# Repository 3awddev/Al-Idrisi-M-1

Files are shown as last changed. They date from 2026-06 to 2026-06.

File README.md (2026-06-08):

# Al-Idrisi-M1 — CanSat Flight Control System

> A complete end-to-end CanSat competition platform: dual-ESP32 flight computer, 3D-printable enclosure, and PyQt6 ground control station with real-time telemetry, 3D visualisation, and simulation.

---

## Table of Contents

1. [For Absolute Beginners](#for-absolute-beginners)
2. [For Aerospace & Software Engineers](#for-aerospace--software-engineers)
   - [Project Overview](#project-overview)
   - [Flight Hardware — Dual ESP32 Architecture](#flight-hardware--dual-esp32-architecture)
   - [3D CAD — Parametric CanSat Enclosure](#3d-cad--parametric-cansat-enclosure)
   - [CFC Software — Ground Control Station](#cfc-software--ground-control-station)
   - [Flight Firmware — Main ESP32](#flight-firmware--main-esp32)
   - [Flight Firmware — ESP32-CAM Coprocessor](#flight-firmware--esp32-cam-coprocessor)
   - [Telemetry & Command Protocols](#telemetry--command-protocols)
   - [Power Budget](#power-budget)
   - [Build Guide](#build-guide)
   - [Competition Workflow](#competition-workflow)

---

## For Absolute Beginners

### What is a CanSat?

A CanSat is a **miniature satellite** that fits inside a standard soda can (67 mm diameter × 120 mm tall). It's launched on a small rocket to ~800 m altitude, then descends by parachute while transmitting sensor data to a ground station on Earth. University and high-school teams worldwide build CanSats for the annual **CanSat Competition** organised by the American Astronomical Society.

Every CanSat must contain:
- A **flight computer** (microcontroller + sensors)
- A **radio** to transmit data back to the ground
- A **parachute** deployment mechanism
- A **battery** to power everything
- A **structural frame** (the "can" body)

### What does this project do?

This project is a **complete CanSat engineering kit** with three main parts:

```
┌─────────────────────────────────────────────────────────┐
│              AL-IDRISI-M1 SYSTEM OVERVIEW                │
├─────────────────────────────────────────────────────────┤
│                                                         │
│  ┌─────────────────┐    433 MHz LoRa    ┌─────────────┐│
│  │  FLIGHT SYSTEM  │ ◄──────────────►   │  GROUND      ││
│  │  (in the can)   │                    │  STATION     ││
│  │                 │                    │  (laptop)    ││
│  │  • ESP32 (main) │                    │              ││
│  │  • ESP32-CAM    │                    │  • Real-time  ││
│  │  • BMP280       │                    │    plots     ││
│  │  • MPU-6050     │                    │  • 3D model   ││
│  │  • INA219       │                    │  • Telemetry  ││
│  │  • NEO-6M GPS   │                    │    console    ││
│  │  • LoRa SX1278  │                    │  • Simulation ││
│  │  • MG90S servo  │                    │  • CSV export ││
│  │  • microSD card │                    │  • Command    ││
│  │  • 2S LiPo batt.│                    │    uplink     ││
│  └────────┬────────┘                    └──────────────┘│
│           │                                              │
│           ▼                                              │
│  ┌─────────────────┐                                     │
│  │  3D-PRINTED     │                                     │
│  │  ENCLOSURE      │                                     │
│  │  (67mm × 120mm) │                                     │
│  │                 │                                     │
│  │  • Electronics  │                                     │
│  │    bay (73mm)   │                                     │
│  │  • Bulkhead     │                                     │
│  │  • Parachute    │                                     │
│  │    bay (38mm)   │                                     │
│  └─────────────────┘                                     │
└─────────────────────────────────────────────────────────┘
```

1. **Flight System** — two ESP32 microcontrollers, sensors, radio, and servo packed inside the can. This is what flies on the rocket.

2. **3D-Printed Enclosure** — the physical can body designed in OpenSCAD. It holds everything together and separates at apogee to deploy the parachute.

3. **Ground Control Station (CFC)** — a desktop application you run on a laptop. It receives radio data, shows live plots, displays a 3D model of the satellite, and lets you send commands back to the CanSat.

### How does it all work?

1. You **program** both ESP32s with the flight firmware (using the Arduino IDE)
2. You **3D-print** the enclosure parts
3. You **assemble** everything inside the can (sensors, batteries, wiring)
4. You **launch** the CanSat on a rocket
5. During ascent, the flight computer **reads sensors** (altitude, temperature, GPS, orientation) and **transmits** all data via LoRa radio every second
6. Your laptop's **ground station** receives, plots, and logs all data in real time
7. At apogee (~800 m), you send a **command via LoRa** to release the parachute
8. The CanSat **descends safely**, streaming data all the way down

---

## For Aerospace & Software Engineers

### Project Overview

**Al-Idrisi-M1** (named after the 12th-century cartographer Muhammad al-Idrisi) is a CanSat Competition 2026 entry. The design uses a **dual-ESP32 architecture** where one ESP32 (NodeMCU-32S) handles all sensors, radio, GPS, servo, and logging, while a second ESP32-CAM (AI-Thinker) handles only the camera — connected via UART.

This architecture was chosen because the ESP32-CAM's camera parallel bus occupies GPIOs 12–15 and 4–5, which would conflict with dedicated SPI (VSPI: 23/19/18/5) and SD card (GPIO15). Splitting the workload avoids all pin conflicts while allowing the main ESP32 full access to VSPI for the LoRa + SD bus.

### Flight Hardware — Dual ESP32 Architecture

#### Block Diagram

```
                         ┌──────────────────────────────────┐
                         │  2S LiPo 7.4V (1000mAh)          │
                         │  ──→ Pololu 5V 2A Regulator      │
                         │       ──→ 5V rail                │
                         └────────────┬──────────┬───────────┘
                                      │          │
               ┌──────────────────────┼──────────┼───────────────────┐
               │        5V            │    5V    │     5V            │
          ┌────▼────┐          ┌──────▼─────┐   ┌▼──────┐           │
          │  Main   │◄──UART──►│ ESP32-CAM  │   │ MG90S │           │
          │  ESP32  │  GPIO16/ │ AI-Thinker │   │ Servo │           │
          │Dev Board│   17     │  OV2640    │   │GPIO25 │           │
          └┬──┬──┬──┘          └────────────┘   └───────┘           │
           │  │  │                                                    │
      ┌────┘  │  └──────┐                                           │
      │       │         │                                            │
 ┌────▼──┐ ┌──▼──┐ ┌───▼──────┐  ┌────────┐                        │
 │ NEO-6M│ │ I2C │ │ LoRa     │  │microSD │                        │
 │  GPS  │ │ Bus │ │ SX1278   │  │(SPI CS │                        │
 │UART1  │ │21/22│ │433MHz SPI│  │GPIO15) │                        │
 │GPIO13/│ │     │ │CS=GPIO5  │  └────────┘                        │
 │  14   │ │ BMP │ │RST=GPIO2 │                                     │
 └───────┘ │280  │ │DIO0=GPIO4│                                     │
           │ MPU-│ └──────────┘                                     │
           │6050 │                                                  │
           │ INA │                                                  │
           │219  │                                                  │
           └─────┘                                                  │
└───────────────────────────────────────────────────────────────────┘
```

#### Component Details

| Component | Interface | Address / Freq | Purpose |
|---|---|---|---|
| **BMP280** | I2C (0x76) | 100 kHz | Barometric pressure + temperature → altitude via standard atmosphere equation |
| **MPU-6050** | I2C (0x68) | 100 kHz | 6-axis IMU: 3-axis gyroscope (±250°/s) + 3-axis accelerometer (±2g) for orientation and dynamics |
| **INA219** | I2C (0x40) | 100 kHz | 0–26V bus voltage, ±3.2A shunt current monitoring |
| **NEO-6M** | UART1 (GPIO13/14) | 9600 8N1 | GPS position, time, altitude, number of satellites. NMEA $GPGGA/$GNGGA parsed onboard |
| **SX1278** | SPI VSPI (CS=5, RST=2, DIO0=4) | 433 MHz, SF7, BW125kHz, CR4/5, 17dBm | LoRa telemetry downlink (1 Hz CSV) + command uplink receiver |
| **microSD** | SPI VSPI (CS=15, shared MOSI/MISO/SCLK) | — | Flight data CSV logging + JPEG image archival |
| **MG90S** | PWM (GPIO25) | 50 Hz | 180° servo for parachute release mechanism |
| **ESP32-CAM** | UART2 (GPIO16/17) | 115200 baud | OV2640 camera, SVGA (800×600) JPEG capture on command, flash LED on GPIO4 |

#### I2C Bus

All three I2C sensors share the same bus (GPIO21 SDA, GPIO22 SCL). Pull-up resistors to 3.3V (4.7 kΩ typical) are required if not present on breakout boards.

| Device | Address | Conflicts |
|---|---|---|
| BMP280 | 0x76 | Jumper to 0x77 if needed |
| MPU-6050 | 0x68 | AD0 high → 0x69 |
| INA219 | 0x40 | A0/A1 strapping → 0x40–0x4F |

#### UART Configuration

| Port | TX | RX | Baud | Device |
|---|---|---|---|---|
| Serial (UART0) | GPIO1 | GPIO3 | 115200 | USB debug / programming |
| UART1 | GPIO14 | GPIO13 | 9600 | NEO-6M GPS |
| UART2 | GPIO17 | GPIO16 | 115200 | ESP32-CAM |

#### SPI Bus

VSPI is shared between LoRa (CS=5) and SD card (CS=15). The bus runs at ESP32 default SPI clock (~10 MHz). Both devices share MOSI (GPIO23), MISO (GPIO19), and SCLK (GPIO18).

#### Key Design Decision — Dual ESP32

The single ESP32-CAM cannot simultaneously drive:
- OV2640 parallel camera bus (GPIOs: 0, 4, 5, 18, 19, 21, 22, 23, 25, 26, 27, 34, 35, 36, 39)
- And VSPI (GPIO 5, 18, 19, 23) for LoRa + SD

The camera bus overlaps with VSPI on GPIOs 5, 18, 19, 23, and with the servo on GPIO25. Adding an SD card would require GPIO15 (another conflict).

**Solution:** A dedicated main ESP32 (NodeMCU-32S) handles all peripherals; the ESP32-CAM handles only the camera. They communicate over UART2 at 115200 baud with a binary protocol.

### 3D CAD — Parametric CanSat Enclosure

#### Design Philosophy

The enclosure is designed exclusively with **OpenSCAD primitives** (cylinder, difference, hull, rotate_extrude) — no external libraries. Every dimension is parameterised at the top of the file. Resolution is set to `$fn=80` for printed parts.

#### Physical Specifications

| Parameter | Value | Tolerance |
|---|---|---|
| Outer diameter | 67 mm | ±0.2 mm (fits standard soda can launcher) |
| Wall thickness | 3 mm | 2 shells with 0.4 mm nozzle |
| Total height | 120 mm | 3 (cap) + 73 (electronics) + 3 (bulkhead) + 38 (parachute) + 3 (cap) |
| Internal diameter | 61 mm | Accommodates 60 mm PCB trays |
| PCB tray PCD | 52 mm | 4× M2.5 threaded inserts |
| Weight (printed) | ~80 g PETG | 0.15 mm layer height |

#### Height Budget

```
z=117 ┌────────────────────┐  ─── Top cap (3 mm)
       │                    │      M3 eye-bolt holes at x=±15
       │   PARACHUTE BAY    │
z= 79  │   38 mm internal   │      Spring seat ring at z=3
       │                    │      Vent hole at mid-height (0°)
       │                    │      Locking pin at z=2 (225°)
z= 76 ─╊━━━━ BULKHEAD 3mm ━╋───  4× M2.5 at 45°, locking pin 
       │                    │      hole at 225°, 6× vent slots
       │ ELECTRONICS BAY    │
       │   73 mm internal   │
       │                    │
       │ Tray 3 @ z=54      │      LoRa module, SD card
       │ Tray 2 @ z=36      │      Main ESP32, BMP280, MPU-6050
       │ Tray 1 @ z=18      │      ESP32-CAM, INA219, Pololu reg
       │                    │
       │ Battery @ z=0-12   │      2S LiPo 54×30×12 mm
z=  0 ─┼────────────────────┼───
z= -3 ─┴────────────────────┴─── Bottom cap (3 mm)
```

#### Cutout Positions (Electronics Bay)

| Feature | Z position (mm) | Angle (°) | Size | Purpose |
|---|---|---|---|---|
| Access port | 40 | 0 | 16×6 mm (rounded) | USB cable during development |
| Camera lens | 20 | 45 | 10 mm Ø | ESP32-CAM OV2640 lens |
| Servo horn | 53 | 75 | 8 mm Ø | MG90S spline access |
| SMA bulkhead | 63.5 | 135 | 11 mm hex | LoRa antenna connector |
| Slide switch | 9.5 | 180 | 13×4 mm (rounded) | Battery power switch |
| LED indicators | 15, 19 | 180 | 3 mm Ø | Status LEDs |
| Battery straps | 5, 15 | 90/270 | 3 mm Ø | Zip-tie anchor points |

#### Threaded Insert Specifications

| Location | Thread | Hole Ø | PCD | Count |
|---|---|---|---|---|
| PCB trays | M2.5 | 2.7 mm | 52 mm | 4 per tray |
| Bulkhead rim (both tubes) | M2.5 | 2.7 mm | 52 mm | 4 per side |
| Top cap (eye bolt) | M3 | 3.2 mm | 30 mm | 2 |
| Bottom cap (tray mount) | M2.5 | 2.7 mm | 52 mm | 4 |

#### Parachute Deployment Mechanism

```
BEFORE RELEASE:                    AFTER RELEASE:

┌────────────────────┐             ┌────────────────────┐
│ Top cap            │             │ Top cap (on ground)│
│ (tethered)         │             │  + parachute       │
│                    │             │                    │
│ Parachute pack     │  Spring     │ ◄─ Spring pushes   │
│  (compressed)      │  ────►      │     parachute out  │
│                    │             │                    │
│┄┄┄ Spring seat ┄┄┄│             │                    │
│                    │             │                    │
│ Locking pin ──►    │             │ Pin retracted      │
│  (through          │             │  by servo push-rod │
│   bulkhead+wall)   │             │                    │
╞═══ BULKHEAD ═══════╡             ╞═══ BULKHEAD ═══════╡
│ Electronics        │             │ Electronics        │
│  (undisturbed)     │             │  (undisturbed)     │
└────────────────────┘             └────────────────────┘

Mechanism:
1. A compression spring sits on the spring-seat ring at z=79
2. The parachute pack is compressed above the spring
3. A 3.5 mm locking pin passes through the upper tube wall at 
   z=78 (225°) and the bulkhead at the same position
4. The MG90S servo at z=53 (75°) actuates a push-rod or 
   Bowden cable that goes through the bulkhead at 225°
5. At apogee, GCS sends "MEC 1 ON" → servo rotates 180°
   → pin retracts → spring pushes parachute out
```

#### Print Settings (Recommended)

| Setting | Value |
|---|---|
| Material | PETG (preferred) or PLA+ |
| Layer height | 0.15 mm |
| Nozzle | 0.4 mm |
| Perimeters | 3 |
| Top/bottom layers | 4 |
| Infill | 20% gyroid |
| Supports | None (design is self-supporting when printed tube-axis-horizontal) |
| Orientation | Tube axis horizontal on bed (`rotate([0,-90,0])` in source) |
| Bed temp | 70°C PETG, 60°C PLA |
| Extruder temp | 235°C PETG, 210°C PLA |

#### OpenSCAD File Structure

The file `cansat_enclosure.scad` is structured as:

```
User Parameters ──► Derived Constants
       │
       ├── Helpers (cr, tube, rh, rs)
       ├── Modules (bottom_cap, top_cap, lower_tube, upper_tube, 
       │            bulkhead, pcb_tray, standoff, parachute_anchor)
       └── Assembly (positions all modules + transparent placeholders)
```

Key design patterns:
- **`rh(d, z, a)`** — Circular radial hole: cylinder of diameter `d` aligned along +X (via `rotate([0,90,0])`), spanning `tube_od×2` (guarantees wall penetration regardless of diameter), rotated to angle `a` about Z, translated to height `z`
- **`rs(w, h, cr, z, a)`** — Rounded-rectangular radial slot: hull of 8 spheres (4 corners × 2 depths ±tube_od) for guaranteed wall penetration
- **Chamfers**: `rotate_extrude` + `polygon` triangle for 1 mm 45° chamfers on tube edges (avoids `difference`-cancellation bug)

### CFC Software — Ground Control Station

The CFC (CanSat Flight Control) is a **PyQt6 desktop application** with pyqtgraph-based real-time plotting, an OpenGL 3D visualisation, serial/LoRa telemetry receiver, command uplink, simulation engine, and CSV logging.

#### Architecture

```
                    ┌─────────────────────────────────────────┐
                    │              QMainWindow                 │
                    │  (src/ui_layout.py)                     │
                    ├──────────┬──────────┬───────────────────┤
                    │ Left     │ Central  │ Right Dock        │
                    │ Dock     │ Area     │ (320px min)       │
                    │ (240px)  │          │                   │
                    ├──────────┼──────────┤  3D Simulation    │
                    │Resources │ Plot Grid│  (GLViewWidget)   │
                    │ Tree     │ (5 plots)│                   │
                    │          │          │  ┌─────────────┐  │
                    │ Hardware │  Altitude│  │ CanSat body  │  │
                    │ Telemetry│   Voltage│  │ + orientation│  │
                    │ Commands │   Current│  │ + altitude   │  │
                    │          │  Accel(3)│  │ + ground     │  │
                    │          │  Gyro(3) │  │ + launch pad │  │
                    └──────────┴──────────┴───────────────────┘
                    │       Bottom Dock ("Console")            │
                    │  ┌──────────────────┬──────────────────┐ │
                    │  │ Message Console  │ Packet Monitor   │ │
                    │  │                  │ Rcvd / Lost / %  │ │
                    │  └──────────────────┴──────────────────┘ │
                    └──────────────────────────────────────────┘
```

#### Dependencies

| Package | Version | Purpose |
|---|---|---|
| `PyQt6` | ≥6.5 | GUI framework (QMainWindow, docks, signals/slots) |
| `pyqtgraph` | ≥0.13 | Real-time plotting + OpenGL 3D view |
| `pandas` | ≥2.0 | In-memory telemetry storage + CSV export |
| `pyserial` | ≥3.5 | Serial port enumeration (QSerialPortInfo) |
| `qdarkstyle` | ≥3.2 | Dark/light theme switching |
| `PyOpenGL` | ≥3.1 | OpenGL context for 3D visualizer |
| `numpy` | *(bundled with pyqtgraph)* | Mesh math, rotation matrices |

Install: `pip install -r requirements.txt`

#### File Map — `src/`

| File | Lines | Responsibility |
|---|---|---|
| `main.py` | 26 | App entry point, QApplication init, dark theme |
| `ui_layout.py` | 435 | MainWindow: toolbars, docks, wire signals, serial port dialog |
| `telemetry_engine.py` | 123 | QThread: serial I/O, mock generator, CSV parsing, poll timer |
| `telemetry_packet.py` | 84 | TelemetryPacket dataclass (22 fields) + `from_csv()` parser |
| `commands.py` | 37 | CommandBuilder (ST, CAL, SIM, SIMP, MEC, CX) + CommandSender signal |
| `mock_generator.py` | 115 | 4-phase flight profile: ascent (30s→300m), release, descent, landed |
| `simulation_engine.py` | 93 | QThread: pressure CSV reader, 1 Hz SIMP uplink |
| `data_logger.py` | 45 | pandas DataFrame: append, sequence checking, CSV export |
| `plots.py` | 132 | BasePlot + 5 specialised plot widgets (altitude, voltage, current, accel, gyro) |
| `visualizer_3d.py` | 430 | OpenGL 3D: Blender-style camera, CanSat mesh with fins + nose cone, auto-rotation |
| `ui_tree.py` | 68 | QTreeWidget: mission/hardware/telemetry/commands trees |
| `ui_console.py` | 77 | MessageConsole + PacketMonitor (received/lost/success %) |

#### Threading Model

```
 ┌──────────────────────┐
 │  MAIN THREAD         │
 │  (QApplication)      │
 │                      │
 │  • UI updates        │
 │  • Plot data append  │
 │  • 3D repaint        │
 │  • Signal handlers   │
 │  • 30ms refresh timer│
 └────────┬─────────────┘
          │ Signals
          │
 ┌────────▼─────────────┐     ┌──────────────────────────┐
 │  TELEMETRY ENGINE    │     │  SIMULATION ENGINE       │
 │  (QThread)           │     │  (QThread)               │
 │                      │     │                          │
 │  • 50ms poll timer   │     │  • 50ms poll timer        │
 │  • Serial read/write │     │  • CSV pressure loading   │
 │  • Mock generation   │     │  • 1 Hz SIMP emission    │
 │  • CSV parsing       │     │                          │
 │  • Command echo      │     │                          │
 └──────────────────────┘     └──────────────────────────┘
```

Both threads use **QTimers** for polling (not blocking loops), which allows clean start/stop from the main thread without join/detach issues. Cross-thread communication is via **Qt Signals** (thread-safe, queued connections).

- `packet_received(TelemetryPacket)` → UI updates, plots, data logger
- `status_message(str)` → Console log
- `serial_error(str)` → Error handling, disconnection
- `command_to_send(str)` → Serial write on telemetry thread
- `pressure_uplink(float)` → SIMP command to flight computer

#### Mock Telemetry Generator

When no serial hardware is available, the `MockGenerator` produces a realistic 4-phase flight profile:

| Time (s) | Phase | Altitude | State | Mode |
|---|---|---|---|---|
| 0–30 | Ascent | 0 → 300 m (linear) | ASCENT | FLIGHT |
| 30–35 | Apogee | 300 m ±5 | RELEASE | FLIGHT |
| 35–120 | Descent | 300 → 0 m (parabolic) | DESCENT | FLIGHT |
| 120+ | Landed | 0 ±0.5 | LANDED | IDLE |

Voltage decays linearly from 16.8 V at 0.6 mV/s (realistic for 2S LiPo under ~350 mA load). All sensor values include Gaussian noise (±0.5°C, ±10 Pa, ±0.02 V, ±0.01 A, ±2°/s gyro, ±1 m/s² accel).

#### 3D Visualizer

The `BlenderStyleGLViewWidget` (subclass of `GLViewWidget`) implements:

| Interaction | Action |
|---|---|
| MMB drag | Orbit camera |
| Shift + MMB drag | Pan (view-upright) |
| Ctrl + MMB drag | Zoom (via `distance` animation) |
| Scroll wheel | Zoom (animated, 0.999^delta factor) |
| Ctrl + scroll | FOV adjustment |
| MMB double-click | Reset to default view (distance=45, elev=15, azimuth=0) |

**Auto-rotation**: When no telemetry has arrived for 2+ seconds, the CanSat model slowly spins (0.5°/tick at 33 ms = ~15°/s) around the Y axis. Real orientation data (roll/pitch/yaw from MPU-6050) immediately suppresses auto-spin.

The 3D scene includes:
- Checkerboard ground plane (80×80 units at z=0)
- Launch pad (3-cylinder stage with green inner ring)
- CanSat body (cylinder mesh, 0.35 radius × 0.80 height, blue)
- Nose cone (red cone, 0.35 radius × 0.35 height)
- 4 tail fins (red, 0.4 span × 0.25 length)
- 2 white stripes (decorative rings)
- Vertical reference line (altitude indicator, translucent blue)
- Axis indicator (3-colour, in corner)

The altitude is scaled by `ALT_SCALE = 10` (1 unit = 10 m real altitude) to keep the model visible within the view frustum.

#### Telemetry Protocol — 22-field CSV

```
TEAM_ID, MISSION_TIME, PACKET_COUNT, MODE, STATE,
ALTITUDE, TEMPERATURE, PRESSURE, VOLTAGE, CURRENT,
GYRO_R, GYRO_P, GYRO_Y, ACCEL_R, ACCEL_P, ACCEL_Y,
GPS_TIME, GPS_ALTITUDE, GPS_LATITUDE, GPS_LONGITUDE,
GPS_SATS, CMD_ECHO
```

Transmitted via LoRa at 1 Hz (every 1000 ms, not polling-loop-gated to avoid drift). The main ESP32 formats the line with `snprintf` and sends it via `LoRa.beginPacket()` / `LoRa.print()` / `LoRa.endPacket()`.

#### Command Protocol

Commands are sent **from GCS → Flight Computer** via LoRa (or serial during testing).

```
CMD,<TEAM_ID>,<ACTION>[,<PARAMETER>]
```

| Command | Example | Action |
|---|---|---|
| ST | `CMD,1234,ST,3600` | Start mission; set mission_time to 3600 s; enter FLIGHT/ASCENT |
| CAL | `CMD,1234,CAL` | Zero IMU bias (gyro/accel) + altimeter |
| SIM ENABLE | `CMD,1234,SIM,ENABLE` | Enter simulation mode (accept SIMP overrides) |
| SIMP | `CMD,1234,SIMP,95000` | Override pressure sensor with 95000 Pa |
| MEC | `CMD,1234,MEC,1,ON` | Set servo to 180° (parachute release) |
| CX | `CMD,1234,CX,ON` | Request camera capture from ESP32-CAM |

#### Simulation Engine

The `SimulationEngine` QThread loads a CSV file with `TIME,PRESSURE` columns and uplinks pressure values at 1 Hz via SIMP commands. This simulates a realistic pressure profile during flight, allowing full GCS testing without a real CanSat or rocket.

The sample file `sample_pressure.csv` contains a 120-second profile: 30 s ascent (1013.25 → 977.00 hPa), 5 s apogee, 55 s descent, 30 s ground.

#### Data Logging

All telemetry is stored in a **pandas DataFrame** (max 600 rows rolling window) and can be exported to CSV via the Export button (`_on_export`). The `DataLogger` tracks packet sequence numbers and reports lost packets (gaps in `PACKET_COUNT`).

### Flight Firmware — Main ESP32

**File:** `flight/main_esp32/main_esp32.ino` (592 lines)

#### Initialisation Sequence

```
1. Serial.begin(115200)               // Debug output
2. Wire.begin(21, 22)                 // I2C at 100 kHz
3. BMP280.begin()                     // Read calib, set normal mode
4. MPU6050.begin()                    // Wake from sleep, set ±250°/s, ±2g
5. INA219.begin()                     // Config: 32V, 3.2A range
6. gps_ser.begin(9600, SERIAL_8N1, 13, 14)
7. cam_ser.begin(115200, SERIAL_8N1, 16, 17)
8. LoRa.setPins(5, 2, 4)             // CS, RST, DIO0
9. LoRa.begin(433E6)                  // SF7, BW125kHz, CR4/5, 17dBm
10. servo.attach(25); servo.write(0)  // MG90S: 0° = closed
11. SD.begin(15)                      // Create /flight/ dir, open CSV
```

#### Main Loop (1 Hz)

```
timer ≥ 1000ms?
├── Read BMP280 → temperature, pressure
│   └── If SIM mode: override pressure from SIMP command
│   └── altitude = 44330 × (1 - (p/p₀)^(1/5.255))
├── Read MPU-6050 → accel_r/p/y, gyro_r/p/y
│   └── Subtract calibration bias
├── Read INA219 → voltage, current
├── Flight state machine:
│   LAUNCH_WAIT + alt ≥ 10m → ASCENT + FLIGHT
├── Format 22-field CSV line
├── LoRa.beginPacket → LoRa.print → LoRa.endPacket
├── Append to SD CSV file
├── Serial.println (debug)
└── process_cam_uart()     // Check for JPEG from ESP32-CAM
```

#### Sensor Drivers (all inline, no libraries)

All three I2C sensor drivers are implemented **from scratch** using `Wire` — no Adafruit or SparkFun libraries. This keeps the firmware self-contained and avoids library version conflicts.

- **BMP280**: Full compensation from factory calibration registers (0x88–0x9F). 20-bit raw pressure/temperature → 32-bit compensated values per Bosch datasheet.
- **MPU-6050**: Direct register reads (0x3B–0x44). FIFO not used (polled reads at 1 Hz). Raw ±2g / ±250°/s.
- **INA219**: 12-bit shunt + bus voltage reads. Shunt voltage → current via 0.1 Ω sense resistor (0.1 mA/LSB).

#### GPS NMEA Parser

Parses `$GPGGA` and `$GNGGA` sentences (up to 256 bytes buffered). Extracts:
- Time (HH:MM:SS from UTC)
- Latitude/Longitude (DDMM.MMMM → DD.DDDDDD)
- Number of satellites
- GPS altitude

DM.MMMM → decimal conversion:
```
lat_dec = floor(raw/100) + (raw - floor(raw/100)*100) / 60
```

#### Image Reception State Machine

Handles the binary protocol from ESP32-CAM (`0xAA 0xBB <4-byte length> <JPEG data> DONE\r\n`). Images are saved to `/flight/img_<timestamp>.jpg` on the microSD card. Buffer: 60 kB (max SVGA JPEG fits within ~50 kB).

```
IMG_HDR1 → 0xAA → IMG_HDR2 → 0xBB → IMG_LEN → (4 bytes) → IMG_DATA → (len bytes) → save to SD → IMG_IDLE
     │          │          │
     └─ no ─────┴─ no ─────┴─ no ────→ IMG_HDR1 (reset)
```

### Flight Firmware — ESP32-CAM Coprocessor

**File:** `flight/esp32_cam/esp32_cam.ino` (123 lines)

#### UART Protocol

| Direction | Message | Response |
|---|---|---|
| Main → CAM | `CX ON\r\n` | `0xAA 0xBB <len:4> <JPEG> DONE\r\n` |
| Main → CAM | `CX OFF\r\n` | `OK\r\n` |

#### Camera Configuration

- **Resolution:** SVGA (800×600)
- **Format:** JPEG
- **Quality:** 12 (good balance of size/clarity)
- **PSRAM:** Required (AI-Thinker board has 4 MB PSRAM)
- **Clock:** XCLK at 20 MHz
- **Brown-out:** Disabled during JPEG transmission (high current draw)

#### Power States

| State | Camera Power | Current Draw |
|---|---|---|
| Idle (CX OFF) | Deinitialised via `esp_camera_deinit()` | ~20 mA |
| Capture (CX ON) | Active via `esp_camera_init()` | ~180 mA |

The flash LED on GPIO4 is illuminated during capture for 200 ms.

### Power Budget

| Component | Idle (mA) | Active (mA) | Notes |
|---|---|---|---|
| Main ESP32 | 50 | 80 | Wi-Fi off, LoRa + SD active |
| ESP32-CAM | 20 | 180 | Camera deinit'd / active + capture |
| LoRa SX1278 | 0.1 | 30 | LowPower idle / TX 17dBm |
| NEO-6M GPS | 45 | 45 | Always on, continuous fix |
| MG90S Servo | 5 | 250 (stalled) | Idle 0°, release 180° |
| 3× I2C sensors | 2 | 5 | BMP280+MPU6050+INA219 |
| **Total** | **~120 mA** | **~590 mA** | Peak with camera + servo |

A **2S 1000 mAh LiPo** provides ~1.7 hours endurance (at average 350 mA). The Pololu 5V 2A regulator handles all loads with margin.

### Build Guide

#### Step 1: 3D Printing

1. Install OpenSCAD from openscad.org
2. Open `C:\Users\El4v\Music\cansat_enclosure.scad`
3. Adjust parameters at top of file if needed (diameters, heights)
4. Press F6 to render (may take 30–60 seconds)
5. Press F7 to export STL
6. Slice in PrusaSlicer / Cura / OrcaSlicer with settings above
7. Print each part: bottom cap, lower tube, upper tube, bulkhead, 3× PCB trays, 12× standoffs, top cap
8. Tap M2.5 holes with M2.5 tap; insert heat-set threaded inserts where needed

#### Step 2: Program ESP32-CAM

1. Connect ESP32-CAM to USB-UART adapter (GPIO0→GND for flash)
2. Open `flight/esp32_cam/esp32_cam.ino` in Arduino IDE
3. Board: `AI-Thinker ESP32-CAM`, Partition: `Huge APP (3MB No OTA)`, PSRAM: Enabled
4. Upload at 115200 baud
5. Remove GPIO0 jumper, press RST

#### Step 3: Program Main ESP32

1. Connect NodeMCU-32S via USB
2. Open `flight/main_esp32/main_esp32.ino` in Arduino IDE
3. Board: `ESP32 Dev Module`, Partition: `Default 4MB with spiffs`
4. Upload at 921600 baud
5. Open Serial Monitor at 115200 baud — verify "BMP280 OK", "MPU6050 OK", "LoRa OK", etc.

#### Step 4: Assemble Electronics

Refer to wiring tables above. Assembly order:
1. Install threaded inserts in 3D-printed parts
2. Mount standoffs + PCB trays inside lower tube
3. Populate components per layout table:
   - Battery floor: 2S LiPo + switch + LEDs (zip-tie through strap holes)
   - Tray 1: ESP32-CAM + INA219 + Pololu regulator
   - Tray 2: Main ESP32 + BMP280 + MPU-6050
   - Tray 3: LoRa module + SD card module
4. Wire all power + I2C + SPI + UART buses
5. Fit bulkhead + upper tube with spring + parachute pack
6. Locking pin through 225° holes (bulkhead + upper tube wall)
7. Attach servo push-rod to locking pin
8. Close with top cap (eye-bolt through M3 holes, shock cord to parachute anchor)
9. Calibrate M2.5 rim screws to hold bulkhead securely

#### Step 5: Install & Run GCS

```bash
cd al-idrisi-m1
pip install -r requirements.txt
python main.py
```

Boot sequence:
1. Window appears with dark theme, 3D dock on right
2. Click **Mock OFF** → becomes **Mock ON** → telemetry starts
3. Plots populate with mock data, 3D model spins (auto-rotation)
4. Click **Connect** → select COM port → real telemetry from flight computer
5. Click **ST** → sends mission start time → flight enters ASCENT mode
6. Click **CAL** → calibrates IMU + altimeter bias
7. Click **SIM** → load pressure CSV → starts simulation mode
8. Click **MEC** → sends servo release command
9. Click **Export CSV** → save flight data for post-analysis

### Competition Workflow

```
PRE-LAUNCH:
1. Power on CanSat → mode = LAUNCH_WAIT
2. Connect GCS → verify telemetry (altitude ~0 m, voltage >7.0 V, GPS fix)
3. Click CAL → capture sensor biases
4. Wait for LCO (Launch Control Officer) countdown

LAUNCH:
5. Rocket lifts off; CanSat accelerates
6. At 10 m altitude → mode auto-switches to ASCENT + FLIGHT
7. GCS plots altitude in real time, 3D model rises above ground

APOGEE (≈800 m, ~30 s after launch):
8. Judge provides pressure CSV for SIMP simulation OR
   Real flight: click MEC 1 ON → servo releases parachute

DESCENT:
9. Parachute deploys, descent rate ≈10 m/s
10. GCS tracks GPS coordinates, 3D model descends
11. On-ground recovery team follows GPS to landing site

POST-FLIGHT:
12. Export CSV → submit to competition judges
13. Retrieve SD card for camera images
14. Print flight log from GCS console
```

---

## Repository Structure

```
al-idrisi-m1/
├── main.py                        # GCS application entry point
├── requirements.txt               # Python dependencies
├── sample_pressure.csv            # 120-second simulation pressure profile
├── README.md                      # This file
├── C:\Users\El4v\Music\cansat_enclosure.scad   # OpenSCAD enclosure
├── flight/
│   ├── README.md                  # Flight system build guide
│   ├── main_esp32/
│   │   └── main_esp32.ino         # Main flight computer firmware
│   └── esp32_cam/
│       └── esp32_cam.ino          # Camera coprocessor firmware
└── src/
    ├── __init__.py
    ├── main.py                    # (re-exported by root main.py)
    ├── ui_layout.py               # MainWindow, docks, toolbars
    ├── telemetry_engine.py         # Serial/mock thread
    ├── telemetry_packet.py         # 22-field dataclass + CSV parser
    ├── commands.py                 # CommandBuilder + CommandSender
    ├── mock_generator.py           # 4-phase mock flight profile
    ├── simulation_engine.py        # Pressure CSV simulation thread
    ├── data_logger.py              # pandas DataFrame logger + export
    ├── plots.py                    # 5 real-time pyqtgraph plots
    ├── visualizer_3d.py            # OpenGL CanSat + auto-rotation
    ├── ui_tree.py                  # Resources QTreeWidget
    └── ui_console.py               # Console + packet monitor
```

---

## License

Educational / competition use. No warranty expressed or implied.

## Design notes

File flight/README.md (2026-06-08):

# CanSat Flight System — ESP32 Dual-Processor

## Architecture

```
                      ┌─────────────────────────────────┐
  4×18650 (4S) ──→    │  Pololu 5V 2A Regulator         │
  12–16.8V             │  (4.5–28V input → 5V output)    │
                      └──────────┬──────────────────────┘
                                 │ 5V rail
              ┌──────────────────┼──────────────────┐
              │                  │                  │
        ┌─────▼──────┐    ┌─────▼──────┐     ┌─────▼──────┐
        │  Main ESP32 │    │ ESP32-CAM  │     │   Servo    │
        │ (DevKitC /  │◄──►│ (AI-Thinker)│     │   MG90S    │
        │  NodeMCU)   │UART│  OV2640    │     │  GPIO25    │
        └──┬──┬──┬──┬─┘    └────────────┘     └────────────┘
           │  │  │  │
      ┌────┘  │  │  └──────┐
      │       │  │         │
 ┌────▼──┐ ┌──▼──▼──┐ ┌───▼────┐  ┌───────────┐
 │  GPS  │ │ I2C Bus│ │  LoRa  │  │  microSD  │
 │ NEO-6M│ │GPIO21/22│ │SX1278  │  │  (SPI CS: │
 │UART1  │ │        │ │SPI VSPI│  │   GPIO15) │
 │GPIO13/│ │ BMP280 │ │GPIO5 CS│  └───────────┘
 │14     │ │ MPU6050│ │GPIO4   │
 └───────┘ │ INA219 │ │DIO0    │
           └────────┘ │GPIO2   │
                      │RST     │
                      └────────┘
```

## Bill of Materials

| Component | Qty | Purpose |
|---|---|---|
| ESP32 Dev Board (NodeMCU-32S / ESP32-DevKitC) | 1 | Main flight computer |
| AI-Thinker ESP32-CAM (OV2640) | 1 | Camera coprocessor |
| BMP280 | 1 | Temperature & pressure sensor (I2C) |
| MPU-6050 | 1 | 6-axis IMU (I2C) |
| INA219 | 1 | Voltage & current sensor (I2C) |
| NEO-6M GPS Module | 1 | GPS receiver (UART) |
| LoRa SX1278 433MHz Module | 1 | Telemetry radio (SPI) |
| MG90S Micro Servo | 1 | Canopy release mechanism |
| 4×18650 Lithium-Ion Cells (4S) | 4 | Battery: 14.8V nom, 16.8V full, 12.0V cut-off |
| Pololu 5V 2A Step-Down Regulator | 1 | Powers both ESP32 boards from 4S battery |
| microSD Card (16GB+) | 1 | Flight data & image logging |
| ¼-wave 433 MHz Antenna | 1 | For LoRa module |
| Passive buzzer (optional) | 1 | Audio feedback |

## Wiring

### Main ESP32 Pinout

| Main ESP32 GPIO | Connection | Peripheral |
|---|---|---|
| GPIO21 (SDA) | SDA bus | BMP280 SDA, MPU-6050 SDA, INA219 SDA |
| GPIO22 (SCL) | SCL bus | BMP280 SCL, MPU-6050 SCL, INA219 SCL |
| GPIO23 (MOSI) | VSPI MOSI | SX1278 MOSI, SD MOSI |
| GPIO19 (MISO) | VSPI MISO | SX1278 MISO, SD MISO |
| GPIO18 (SCLK) | VSPI SCLK | SX1278 SCLK, SD SCLK |
| GPIO5 (CS) | SPI CS | SX1278 NSS |
| GPIO15 (CS) | SPI CS | microSD card CS |
| GPIO4 | DIO0 | SX1278 DIO0 (interrupt) |
| GPIO2 | RST | SX1278 Reset |
| GPIO13 (RX1) | UART1 RX | NEO-6M GPS TX (yellow) |
| GPIO14 (TX1) | UART1 TX | NEO-6M GPS RX (green) |
| GPIO16 (RX2) | UART2 RX | ESP32-CAM TX (GPIO1) |
| GPIO17 (TX2) | UART2 TX | ESP32-CAM RX (GPIO3) |
| GPIO25 | PWM | MG90S servo signal (orange) |
| 5V/VIN | Power | Pololu 5V output |
| GND | Ground | Common ground rail |

### ESP32-CAM Pinout

| ESP32-CAM GPIO | Connection | Peripheral |
|---|---|---|
| GPIO1 (TX0) | UART TX | Main ESP32 GPIO16 (RX2) |
| GPIO3 (RX0) | UART RX | Main ESP32 GPIO17 (TX2) |
| GPIO4 | Output | Built-in flash LED |
| 5V | Power | Pololu 5V output |
| GND | Ground | Common ground rail |

### I2C Bus (shared, addresses)

| Device | Address | Notes |
|---|---|---|
| BMP280 | 0x76 | Alt jumper for 0x77 |
| MPU-6050 | 0x68 | AD0 low = 0x68 |
| INA219 | 0x40 | A0/A1 GND = 0x40 |

### Power Distribution

```
4S 18650 (12–16.8V) ──→ Pololu VIN
                           Pololu VOUT (5V) ──→ Main ESP32 5V/VIN
                                              ──→ ESP32-CAM 5V pin
                                              ──→ Servo VCC (5V)
                                              ──→ NEO-6M VCC (3.3V via regulator)
                                              ──→ LoRa VCC (3.3V via regulator)
                                              ──→ BMP280, MPU-6050, INA219 VCC (3.3V)
```

**Note:** All 3.3V sensors/modules share the ESP32's 3.3V rail (the on-board regulator supplies ~150mA, sufficient for these low-power sensors). For LoRa + GPS, use a separate 3.3V regulator (AMS1117-3.3) if total 3.3V draw exceeds 150mA.

### Power Budget

| Component | Current (mA) |
|---|---|
| Main ESP32 (average) | ~80 |
| ESP32-CAM (camera on, no flash) | ~180 |
| LoRa SX1278 (TX) | ~30 |
| NEO-6M GPS | ~45 |
| MG90S servo (idle) | ~10 |
| MG90S servo (stalled) | ~250 |
| BMP280 + MPU-6050 + INA219 | ~5 |
| **Total (typical)** | **~350 mA** |
| **Total (peak, servo+LoRa+camera)** | **~800 mA** |

Pololu 5V 2A rating covers all scenarios.

## Programming

### Software Dependencies

**Arduino IDE** (or PlatformIO) with ESP32 board support:
- Board URL: `https://raw.githubusercontent.com/espressif/arduino-esp32/gh-pages/package_esp32_index.json`

**Arduino Libraries:**
- `LoRa` by Sandeep Mistry (for SX1278)
- `ESP32Servo` by Kevin Harrington
- Built-in: `SPI`, `Wire`, `SD`, `HardwareSerial`

### Main ESP32

1. Open `flight/main_esp32/main_esp32.ino` in Arduino IDE
2. Board: `ESP32 Dev Module` (or your specific dev board)
3. Flash Size: `4MB`
4. Partition Scheme: `Default 4MB with spiffs`
5. Upload Speed: `921600`
6. Select correct COM port
7. **Do not connect ESP32-CAM's UART** during programming (conflicts with serial upload)
8. Click Upload

### ESP32-CAM

1. Open `flight/esp32_cam/esp32_cam.ino` in Arduino IDE
2. Board: `AI-Thinker ESP32-CAM`
3. Flash Size: `4MB`
4. Partition Scheme: `Huge APP (3MB No OTA)`
5. Upload Speed: `115200`
6. **GPIO0 must be LOW during upload** (hold boot button or connect GPIO0 to GND)
7. Click Upload, then press ESP32-CAM RST
8. After flashing, set GPIO0 HIGH and RST

### First-time setup

1. Program ESP32-CAM first (standalone, via its UART-to-USB adapter)
2. Program Main ESP32 (standalone via its USB port)
3. Wire everything together
4. Power on — both ESP32s boot autonomously
5. Open Main ESP32 Serial Monitor (115200 baud) to see boot messages

## Telemetry Protocol

22-field CSV, transmitted via LoRa at 1 Hz:

```
TEAM_ID,MISSION_TIME,PACKET_COUNT,MODE,STATE,
ALTITUDE,TEMPERATURE,PRESSURE,VOLTAGE,CURRENT,
GYRO_R,GYRO_P,GYRO_Y,ACCEL_R,ACCEL_P,ACCEL_Y,
GPS_TIME,GPS_ALTITUDE,GPS_LATITUDE,GPS_LONGITUDE,
GPS_SATS,CMD_ECHO
```

Example:
```
1234,3600,1,FLIGHT,ASCENT,150.25,18.5,101325,16.5,0.2,0.1,-0.2,0.3,0.0,0.0,9.81,12:30:00,152.3,40.4432,-79.9428,10,
```

## Command Protocol

Commands received via LoRa, format:
```
CMD,<TEAM_ID>,<ACTION>[,<PARAM>]
```

| Command | Parameters | Description |
|---|---|---|
| `ST` | `<time_s>` | Start mission, set time, enter FLIGHT/ASCENT |
| `CAL` | *(none)* | Calibrate IMU + altimeter bias |
| `SIM ENABLE` | *(none)* | Enter simulation mode |
| `SIMP` | `<pressure>` | Override pressure sensor (Pa) |
| `MEC` | `<device>,ON/OFF` | Mechanism control (servo 0°/180°) |
| `CX` | `ON` or `OFF` | Camera capture / standby |

## Camera Protocol (Main ESP32 ↔ ESP32-CAM)

**Main** → **CAM**: `CX ON\r\n` or `CX OFF\r\n`

**CAM** → **Main** (CX ON):
```
0xAA 0xBB <uint32_t length (big-endian)> <JPEG bytes> "DONE\r\n"
```

**CAM** → **Main** (CX OFF):
```
"OK\r\n"
```

Images saved to `/flight/img_<timestamp>.jpg` on microSD.

## State Machine

```
LAUNCH_WAIT ──(altitude ≥ 10m)──→ ASCENT ──(MEC ON)──→ RELEASE ──(descent)──→ DESCENT ──(ground)──→ LANDED
```

## GPIO Reference Summary

### Main ESP32

| Pin | Function | Notes |
|---|---|---|
| 21 | I2C SDA | BMP280, MPU6050, INA219 |
| 22 | I2C SCL | |
| 23 | SPI MOSI | LoRa + SD (shared bus) |
| 19 | SPI MISO | |
| 18 | SPI SCLK | |
| 5 | LoRa CS | |
| 15 | SD CS | |
| 4 | LoRa DIO0 | RxDone interrupt |
| 2 | LoRa RST | |
| 13 | GPS RX | UART1 from GPS TX |
| 14 | GPS TX | UART1 to GPS RX |
| 16 | CAM RX | UART2 from ESP32-CAM TX |
| 17 | CAM TX | UART2 to ESP32-CAM RX |
| 25 | Servo PWM | MG90S signal wire |

### ESP32-CAM

| Pin | Function | Notes |
|---|---|---|
| 1 | TX0 | UART to Main ESP32 RX2 |
| 3 | RX0 | UART from Main ESP32 TX2 |
| 4 | Flash LED | Built-in flash, optional |

## Troubleshooting

| Symptom | Likely Cause | Fix |
|---|---|---|
| No LoRa TX | SX1278 not initialized | Check SPI wiring, 3.3V, antenna |
| No GPS fix | UART baud mismatch | NEO-6M defaults to 9600 8N1 |
| ESP32-CAM no response | UART crossed | Swap TX/RX between boards |
| SD card fails | CS pin wrong | Check SPI CS assignment |
| Brownout/reset | 5V rail sagging | Check Pololu output, battery voltage >12V |
| Camera no image | PSRAM not enabled | Enable PSRAM in Arduino IDE tools menu |
| Serial upload fails | UART conflict | Disconnect ESP32-CAM TX/RX during upload |

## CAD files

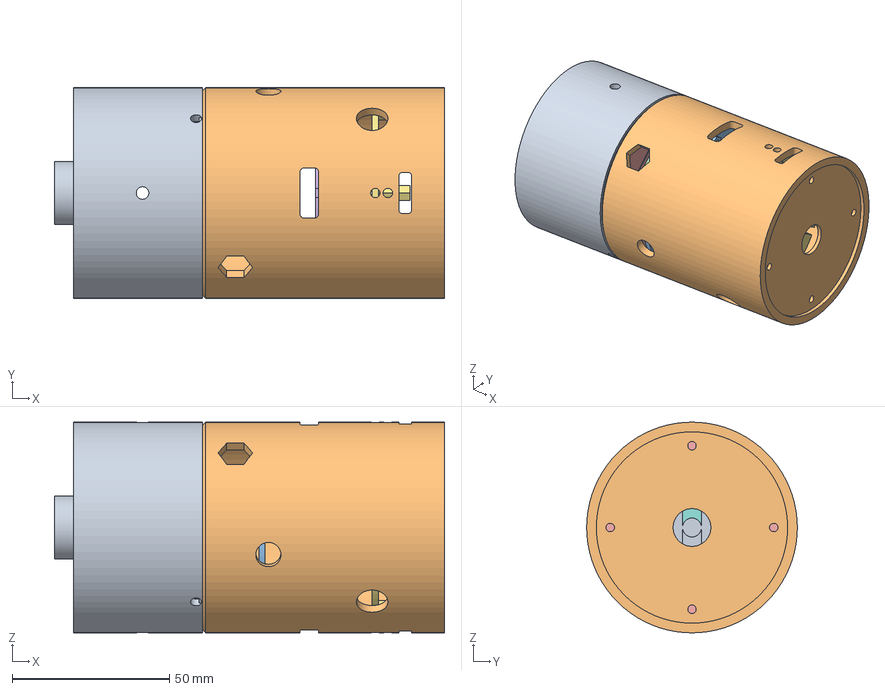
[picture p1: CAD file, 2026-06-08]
cad/cansat_enclosure.3mf
124.0 x 67.0 x 67.0 mm
Mesh_body_07
Mesh_body_04
Mesh_body_03
Mesh_body_05
Mesh_body_02
Mesh_body_01
Mesh_body_06
Mesh_body_08

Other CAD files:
cad/cansat_enclosure.stl

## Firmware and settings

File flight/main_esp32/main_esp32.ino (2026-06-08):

/*
  CanSat Main Flight Computer — ESP32
  Sensors:  BMP280, MPU-6050, INA219 (I2C)
  Radio:    SX1278 LoRa (SPI)
  GPS:      NEO-6M (UART1)
  Camera:   ESP32-CAM (UART2)
  Servo:    MG90S (PWM)
  Logging:  microSD (SPI)
*/

#include <Wire.h>
#include <SPI.h>
#include <SD.h>
#include <LoRa.h>
#include <ESP32Servo.h>

// ── Pin mapping ────────────────────────────────────────────────────────
// I2C:           GPIO21(SDA), GPIO22(SCL)
// VSPI (LoRa):   GPIO23(MOSI), GPIO19(MISO), GPIO18(SCLK), GPIO5(CS)
// VSPI (SD):     share MOSI/MISO/SCLK, GPIO15(SD_CS)
#define LORA_CS   5
#define LORA_RST  2
#define LORA_DIO0 4
#define SD_CS     15
#define SERVO_PIN 25
#define GPS_RX    13  // UART1 RX
#define GPS_TX    14  // UART1 TX
#define CAM_RX    16  // UART2 RX
#define CAM_TX    17  // UART2 TX

// ── Constants ─────────────────────────────────────────────────────────
#define TEAM_ID      1234
#define GPS_BAUD     9600
#define CAM_BAUD     115200
#define LORA_FREQ    433E6
#define TLM_INTERVAL 1000
#define LOG_DIR      "/flight"

static const char TLM_HEADER[] PROGMEM =
    "TEAM_ID,MISSION_TIME,PACKET_COUNT,MODE,STATE,"
    "ALTITUDE,TEMPERATURE,PRESSURE,VOLTAGE,CURRENT,"
    "GYRO_R,GYRO_P,GYRO_Y,ACCEL_R,ACCEL_P,ACCEL_Y,"
    "GPS_TIME,GPS_ALTITUDE,GPS_LATITUDE,GPS_LONGITUDE,"
    "GPS_SATS,CMD_ECHO";

// ── I2C addresses ─────────────────────────────────────────────────────
#define BMP280_ADDR   0x76
#define MPU6050_ADDR  0x68
#define INA219_ADDR   0x40

// ── Flight state ──────────────────────────────────────────────────────
struct FlightState {
    uint32_t mission_time = 0;
    uint32_t packet_count = 0;
    char mode[16] = "NONE";
    char state_str[16] = "LAUNCH_WAIT";
    float altitude = 0.0f;
    float temperature = 20.0f;
    float pressure = 101325.0f;
    float voltage = 16.8f;
    float current = 0.0f;
    float gyro_r = 0.0f, gyro_p = 0.0f, gyro_y = 0.0f;
    float accel_r = 0.0f, accel_p = 0.0f, accel_y = 9.81f;
    char gps_time[16] = "00:00:00";
    float gps_altitude = 0.0f;
    float gps_latitude = 0.0f;
    float gps_longitude = 0.0f;
    int gps_sats = 0;
    char cmd_echo[128] = "";
    bool sim_enabled = false;
    float sim_pressure = 0.0f;
    float cal_bias_alt = 0.0f;
    float cal_bias_accel[3] = {0, 0, 0};
    float cal_bias_gyro[3] = {0, 0, 0};
    bool img_captured = false;
    bool running = true;
};

static FlightState st;
static float base_pressure = 101325.0f;
static Servo servo;
static File csv_file;

// ── Image receive state machine ───────────────────────────────────────
enum ImgState { IMG_IDLE, IMG_HDR1, IMG_HDR2, IMG_LEN, IMG_DATA };
static ImgState img_state = IMG_IDLE;
static uint32_t img_len = 0, img_received = 0;
static int img_len_cnt = 0;
static uint8_t img_buf[60000];
static bool receiving_img = false;

// ── BMP280 driver ────────────────────────────────────────────────────
class BMP280 {
    int16_t dig_T1, dig_T2, dig_T3, dig_P1, dig_P2, dig_P3, dig_P4,
            dig_P5, dig_P6, dig_P7, dig_P8, dig_P9;
public:
    bool begin() {
        Wire.beginTransmission(BMP280_ADDR);
        if (Wire.endTransmission() != 0) return false;
        uint8_t id = read_reg(0xD0);
        if (id != 0x58) return false;
        read_calib();
        write_reg(0xF4, 0x27);   // ctrl: normal, oversample x1
        write_reg(0xF5, 0xA0);   // config: filter off
        return true;
    }

    void read(float *temp, float *pres) {
        uint8_t d[6];
        Wire.beginTransmission(BMP280_ADDR);
        Wire.write(0xF7);
        Wire.endTransmission();
        Wire.requestFrom(BMP280_ADDR, 6);
        for (int i = 0; i < 6; i++) d[i] = Wire.read();

        int32_t raw_p = ((int32_t)d[0] << 12) | ((int32_t)d[1] << 4) | (d[2] >> 4);
        int32_t raw_t = ((int32_t)d[3] << 12) | ((int32_t)d[4] << 4) | (d[5] >> 4);

        int32_t v1 = (((raw_t >> 3) - ((int32_t)dig_T1 << 1)) * (int32_t)dig_T2) >> 11;
        int32_t v2 = (((((raw_t >> 4) - (int32_t)dig_T1) * ((raw_t >> 4) - (int32_t)dig_T1)) >> 12) * (int32_t)dig_T3) >> 14;
        int32_t t_fine = v1 + v2;
        *temp = (t_fine * 5 + 128) >> 8;
        *temp /= 100.0f;

        v1 = t_fine - 128000;
        v2 = v1 * v1 * (int32_t)dig_P6 >> 6;
        v2 += v1 * (int32_t)dig_P5 << 1;
        v2 = (v2 >> 2) + ((int32_t)dig_P4 << 16);
        v1 = (((int32_t)dig_P3 * ((v1 * v1) >> 12)) >> 11) + ((int32_t)dig_P2 * v1 >> 1);
        v1 >>= 15;

        if (v1 == 0) { *pres = 0; return; }
        uint32_t p = (((1048576 - raw_p) - (v2 >> 12))) * 3125;
        if (p < 0x80000000) p = (p << 1) / (uint32_t)v1;
        else p = (p / (uint32_t)v1) * 2;
        v1 = ((int32_t)dig_P9 * ((int32_t)((p >> 3) * (p >> 3)) >> 13)) >> 12;
        v2 = ((int32_t)(p >> 2) * (int32_t)dig_P8) >> 13;
        *pres = (float)(p + ((v1 + v2 + (int32_t)dig_P7) >> 4));
    }

private:
    void read_calib() {
        Wire.beginTransmission(BMP280_ADDR);
        Wire.write(0x88);
        Wire.endTransmission();
        Wire.requestFrom(BMP280_ADDR, 24);
        uint8_t r[24];
        for (int i = 0; i < 24; i++) r[i] = Wire.read();
        dig_T1 = r[0] | (r[1] << 8);
        dig_T2 = (int16_t)(r[2] | (r[3] << 8));
        dig_T3 = (int16_t)(r[4] | (r[5] << 8));
        dig_P1 = r[6] | (r[7] << 8);
        dig_P2 = (int16_t)(r[8] | (r[9] << 8));
        dig_P3 = (int16_t)(r[10] | (r[11] << 8));
        dig_P4 = (int16_t)(r[12] | (r[13] << 8));
        dig_P5 = (int16_t)(r[14] | (r[15] << 8));
        dig_P6 = (int16_t)(r[16] | (r[17] << 8));
        dig_P7 = (int16_t)(r[18] | (r[19] << 8));
        dig_P8 = (int16_t)(r[20] | (r[21] << 8));
        dig_P9 = (int16_t)(r[22] | (r[23] << 8));
    }

    uint8_t read_reg(uint8_t reg) {
        Wire.beginTransmission(BMP280_ADDR);
        Wire.write(reg);
        Wire.endTransmission();
        Wire.requestFrom(BMP280_ADDR, 1);
        return Wire.read();
    }

    void write_reg(uint8_t reg, uint8_t val) {
        Wire.beginTransmission(BMP280_ADDR);
        Wire.write(reg);
        Wire.write(val);
        Wire.endTransmission();
    }
};

// ── MPU-6050 driver ──────────────────────────────────────────────────
class MPU6050 {
public:
    bool begin() {
        Wire.beginTransmission(MPU6050_ADDR);
        if (Wire.endTransmission() != 0) return false;
        write_reg(0x6B, 0x00);
        delay(100);
        write_reg(0x19, 0x07);
        write_reg(0x1A, 0x00);
        write_reg(0x1B, 0x00);
        write_reg(0x1C, 0x00);
        return true;
    }

    void read(float *ax, float *ay, float *az, float *gx, float *gy, float *gz) {
        Wire.beginTransmission(MPU6050_ADDR);
        Wire.write(0x3B);
        Wire.endTransmission();
        Wire.requestFrom(MPU6050_ADDR, 14);
        int16_t raw[7];
        for (int i = 0; i < 7; i++) raw[i] = (Wire.read() << 8) | Wire.read();
        *ax = raw[0] / 16384.0f;
        *ay = raw[1] / 16384.0f;
        *az = raw[2] / 16384.0f;
        *gx = raw[4] / 131.0f;
        *gy = raw[5] / 131.0f;
        *gz = raw[6] / 131.0f;
    }

private:
    void write_reg(uint8_t reg, uint8_t val) {
        Wire.beginTransmission(MPU6050_ADDR);
        Wire.write(reg);
        Wire.write(val);
        Wire.endTransmission();
    }
};

// ── INA219 driver ───────────────────────────────────────────────────
class INA219 {
public:
    bool begin() {
        Wire.beginTransmission(INA219_ADDR);
        if (Wire.endTransmission() != 0) return false;
        write_reg(0x00, 0x399F);
        write_reg(0x05, 4096);
        return true;
    }

    void read(float *voltage, float *current) {
        uint16_t raw_bus = read_reg(0x02);
        *voltage = ((raw_bus >> 3) * 4) / 1000.0f;
        int16_t raw_shunt = (int16_t)read_reg(0x01);
        *current = raw_shunt * 0.0001f;
        if (*current < 0) *current = 0;
    }

private:
    uint16_t read_reg(uint8_t reg) {
        Wire.beginTransmission(INA219_ADDR);
        Wire.write(reg);
        Wire.endTransmission();
        Wire.requestFrom(INA219_ADDR, 2);
        return (Wire.read() << 8) | Wire.read();
    }

    void write_reg(uint8_t reg, uint16_t val) {
        Wire.beginTransmission(INA219_ADDR);
        Wire.write(reg);
        Wire.write(val >> 8);
        Wire.write(val & 0xFF);
        Wire.endTransmission();
    }
};

// ── Globals ─────────────────────────────────────────────────────────
static BMP280 bmp;
static MPU6050 mpu;
static INA219 ina;
static bool bmp_ok = false, mpu_ok = false, ina_ok = false;
static HardwareSerial gps_ser(1);
static HardwareSerial cam_ser(2);

// ── NMEA parser ─────────────────────────────────────────────────────
void parse_nmea(const char *sentence) {
    if (sentence[0] != '$') return;
    if (!(strstr(sentence, "$GPGGA") || strstr(sentence, "$GNGGA"))) return;

    char buf[96];
    strncpy(buf, sentence, sizeof(buf) - 1);
    buf[sizeof(buf) - 1] = '\0';

    char *parts[15];
    int n = 0;
    char *p = strtok(buf, ",");
    while (p && n < 15) { parts[n++] = p; p = strtok(NULL, ","); }
    if (n < 15) return;

    if (strlen(parts[1]) >= 6) {
        char t[16];
        snprintf(t, sizeof(t), "%.2s:%.2s:%.2s", parts[1], parts[1] + 2, parts[1] + 4);
        strcpy(st.gps_time, t);
    }

    if (strlen(parts[2]) && strlen(parts[3])) {
        float lat = atof(parts[2]);
        int deg = (int)(lat / 100);
        float lat_dec = deg + (lat - deg * 100) / 60.0f;
        if (parts[3][0] == 'S') lat_dec *= -1;
        st.gps_latitude = lat_dec;
    }

    if (strlen(parts[4]) && strlen(parts[5])) {
        float lon = atof(parts[4]);
        int deg = (int)(lon / 100);
        float lon_dec = deg + (lon - deg * 100) / 60.0f;
        if (parts[5][0] == 'W') lon_dec *= -1;
        st.gps_longitude = lon_dec;
    }

    if (strlen(parts[7])) st.gps_sats = atoi(parts[7]);
    if (strlen(parts[9])) st.gps_altitude = atof(parts[9]);
}

// ── Altitude from pressure ──────────────────────────────────────────
static float altitude_from_pressure(float press, float base) {
    return 44330.0f * (1.0f - pow(press / base, 1.0f / 5.255f));
}

// ── Format telemetry CSV ────────────────────────────────────────────
static void format_telemetry(char *out, size_t len) {
    snprintf(out, len,
        "%d,%u,%u,%s,%s,%.2f,%.2f,%.2f,%.3f,%.3f,"
        "%.3f,%.3f,%.3f,%.3f,%.3f,%.3f,"
        "%s,%.2f,%.6f,%.6f,%d,%s",
        TEAM_ID, st.mission_time, st.packet_count,
        st.mode, st.state_str,
        st.altitude, st.temperature, st.pressure,
        st.voltage, st.current,
        st.gyro_r, st.gyro_p, st.gyro_y,
        st.accel_r, st.accel_p, st.accel_y,
        st.gps_time, st.gps_altitude,
        st.gps_latitude, st.gps_longitude,
        st.gps_sats, st.cmd_echo);
}

// ── Execute command ─────────────────────────────────────────────────
void execute_command(const char *cmd) {
    if (strncmp(cmd, "CMD", 3) != 0) return;

    char buf[128];
    strncpy(buf, cmd, sizeof(buf) - 1);
    buf[sizeof(buf) - 1] = '\0';

    char *parts[8];
    int n = 0;
    char *p = strtok(buf, ",");
    while (p && n < 8) { parts[n++] = p; p = strtok(NULL, ","); }
    if (n < 3) return;

    int tid = atoi(parts[1]);
    if (tid != TEAM_ID) return;

    strcpy(st.cmd_echo, cmd);

    const char *action = parts[2];

    if (strcmp(action, "ST") == 0 && n >= 4) {
        st.mission_time = atol(parts[3]);
        strcpy(st.mode, "FLIGHT");
        strcpy(st.state_str, "ASCENT");
    } else if (strcmp(action, "CAL") == 0) {
        st.cal_bias_accel[0] = st.accel_r;
        st.cal_bias_accel[1] = st.accel_p;
        st.cal_bias_accel[2] = st.accel_y;
        st.cal_bias_gyro[0] = st.gyro_r;
        st.cal_bias_gyro[1] = st.gyro_p;
        st.cal_bias_gyro[2] = st.gyro_y;
        st.cal_bias_alt = st.altitude;
    } else if (strcmp(action, "SIM") == 0 && n >= 4) {
        if (strcmp(parts[3], "ENABLE") == 0) {
            st.sim_enabled = true;
            strcpy(st.mode, "SIMULATION");
        }
    } else if (strcmp(action, "SIMP") == 0 && n >= 4) {
        st.sim_pressure = atof(parts[3]);
    } else if (strcmp(action, "MEC") == 0 && n >= 5) {
        if (strcmp(parts[4], "ON") == 0) {
            servo.write(180);
            strcpy(st.state_str, "RELEASE");
        } else {
            servo.write(0);
        }
    } else if (strcmp(action, "CX") == 0) {
        const char *cx_state = (n >= 4) ? parts[3] : "ON";
        cam_ser.print("CX ");
        cam_ser.print(cx_state);
        cam_ser.println();
        if (strcmp(cx_state, "ON") == 0) {
            st.img_captured = false;
            receiving_img = true;
            img_state = IMG_HDR1;
            img_len = 0;
            img_received = 0;
        } else {
            receiving_img = false;
            img_state = IMG_IDLE;
        }
    }

    st.mission_time = millis() / 1000;
}

// ── Process incoming image bytes from ESP32-CAM ─────────────────────
void process_cam_uart() {
    if (!receiving_img) return;

    while (cam_ser.available() && img_state != IMG_DONE) {
        uint8_t b = cam_ser.read();

        switch (img_state) {
            case IMG_HDR1:
                if (b == 0xAA) img_state = IMG_HDR2;
                break;
            case IMG_HDR2:
                if (b == 0xBB) { img_state = IMG_LEN; img_len = 0; img_len_cnt = 0; }
                else img_state = IMG_HDR1;
                break;
            case IMG_LEN:
                img_len = (img_len << 8) | b;
                if (++img_len_cnt >= 4) img_state = IMG_DATA;
                break;
            case IMG_DATA:
                if (img_received < sizeof(img_buf)) img_buf[img_received++] = b;
                if (img_received >= img_len) {
                    // Save image to SD
                    char fname[64];
                    snprintf(fname, sizeof(fname), "%s/img_%lu.jpg", LOG_DIR, millis() / 1000);
                    File img_file = SD.open(fname, FILE_WRITE);
                    if (img_file) {
                        img_file.write(img_buf, img_len);
                        img_file.close();
                    }
                    st.img_captured = true;
                    receiving_img = false;
                    img_state = IMG_IDLE;
                    img_received = 0;
                }
                break;
        }
    }
}

// ── Setup ───────────────────────────────────────────────────────────
void setup() {
    Serial.begin(115200);
    delay(1000);

    // ── I2C ──
    Wire.begin(21, 22);
    Wire.setClock(100000);

    // ── Sensors ──
    bmp_ok = bmp.begin();
    if (bmp_ok) Serial.println("BMP280 OK");
    else Serial.println("BMP280 FAIL");

    mpu_ok = mpu.begin();
    if (mpu_ok) Serial.println("MPU6050 OK");
    else Serial.println("MPU6050 FAIL");

    ina_ok = ina.begin();
    if (ina_ok) Serial.println("INA219 OK");
    else Serial.println("INA219 FAIL");

    // ── GPS UART ──
    gps_ser.begin(GPS_BAUD, SERIAL_8N1, GPS_RX, GPS_TX);

    // ── ESP32-CAM UART ──
    cam_ser.begin(CAM_BAUD, SERIAL_8N1, CAM_RX, CAM_TX);

    // ── LoRa ──
    LoRa.setPins(LORA_CS, LORA_RST, LORA_DIO0);
    if (!LoRa.begin(LORA_FREQ)) {
        Serial.println("LoRa init failed!");
    } else {
        LoRa.setSpreadingFactor(7);
        LoRa.setSignalBandwidth(125E3);
        LoRa.setCodingRate4(5);
        LoRa.setTxPower(17);
        Serial.println("LoRa OK");
    }

    // ── Servo ──
    servo.attach(SERVO_PIN);
    servo.write(0);

    // ── SD card ──
    if (!SD.begin(SD_CS)) {
        Serial.println("SD init failed!");
    } else {
        SD.mkdir(LOG_DIR);
        char fname[64];
        snprintf(fname, sizeof(fname), "%s/flight_%lu.csv", LOG_DIR, millis() / 1000);
        csv_file = SD.open(fname, FILE_WRITE);
        if (csv_file) {
            csv_file.println(FPSTR(TLM_HEADER));
            csv_file.flush();
            Serial.print("Logging to "); Serial.println(fname);
        }
    }

    Serial.println("CanSat ESP32 ready");
}

// ── Main loop ───────────────────────────────────────────────────────
static uint32_t last_tlm = 0;
static char gps_buf[256];
static int gps_idx = 0;

void loop() {
    uint32_t now = millis();

    // ── Read GPS ──
    while (gps_ser.available()) {
        char c = gps_ser.read();
        if (gps_idx < (int)sizeof(gps_buf) - 1) gps_buf[gps_idx++] = c;
        if (c == '\n') {
            gps_buf[gps_idx] = '\0';
            gps_idx = 0;
            parse_nmea(gps_buf);
        }
    }

    // ── Read sensors + send telemetry at 1 Hz ──
    if (now - last_tlm >= TLM_INTERVAL) {
        last_tlm = now;
        st.mission_time = now / 1000;

        // BMP280
        if (bmp_ok) {
            float t, p;
            bmp.read(&t, &p);
            st.temperature = t;
            if (st.sim_enabled && st.sim_pressure > 0) p = st.sim_pressure;
            st.pressure = p;
            float alt = altitude_from_pressure(p, base_pressure);
            alt -= st.cal_bias_alt;
            st.altitude = (alt > 0) ? alt : 0;
        }

        // MPU-6050
        if (mpu_ok) {
            float ax, ay, az, gx, gy, gz;
            mpu.read(&ax, &ay, &az, &gx, &gy, &gz);
            st.accel_r = ax - st.cal_bias_accel[0];
            st.accel_p = ay - st.cal_bias_accel[1];
            st.accel_y = az - st.cal_bias_accel[2];
            st.gyro_r = gx - st.cal_bias_gyro[0];
            st.gyro_p = gy - st.cal_bias_gyro[1];
            st.gyro_y = gz - st.cal_bias_gyro[2];
        }

        // INA219
        if (ina_ok) {
            float v, c;
            ina.read(&v, &c);
            st.voltage = v;
            st.current = c;
        }

        // State machine
        st.packet_count++;
        if (st.altitude >= 10.0f && strcmp(st.state_str, "LAUNCH_WAIT") == 0) {
            strcpy(st.state_str, "ASCENT");
            strcpy(st.mode, "FLIGHT");
            base_pressure = st.pressure;
        }

        // Format and send
        char csv_line[256];
        format_telemetry(csv_line, sizeof(csv_line));

        // LoRa
        LoRa.beginPacket();
        LoRa.print(csv_line);
        LoRa.endPacket(false);

        // SD
        if (csv_file) {
            csv_file.println(csv_line);
            csv_file.flush();
        }

        // Serial debug
        Serial.println(csv_line);
    }

    // ── Receive image from ESP32-CAM ──
    process_cam_uart();

    // ── Check for LoRa commands ──
    int packet_size = LoRa.parsePacket();
    if (packet_size > 0) {
        char cmd[128];
        int i = 0;
        while (LoRa.available() && i < (int)sizeof(cmd) - 1) {
            cmd[i++] = (char)LoRa.read();
        }
        cmd[i] = '\0';
        execute_command(cmd);
    }
}

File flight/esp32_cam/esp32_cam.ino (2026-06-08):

/*
  ESP32-CAM Camera Coprocessor
  Communicates with Main ESP32 over UART.
  Protocol:
    RX: "CX ON\r\n"  → capture JPEG → send 0xAA 0xBB + uint32_t len + data + "DONE\r\n"
    RX: "CX OFF\r\n" → camera sleep → "OK\r\n"
*/

#include "esp_camera.h"
#include "soc/soc.h"
#include "soc/rtc_cntl_reg.h"

#define CAM_BAUD 115200
#define FLASH_LED 4

// AI-Thinker ESP32-CAM pin config
static const camera_config_t camera_config = {
    .pin_pwdn = -1,
    .pin_reset = -1,
    .pin_xclk = 0,
    .pin_sscb_sda = 26,
    .pin_sscb_scl = 27,
    .pin_d7 = 35,
    .pin_d6 = 34,
    .pin_d5 = 39,
    .pin_d4 = 36,
    .pin_d3 = 21,
    .pin_d2 = 19,
    .pin_d1 = 18,
    .pin_d0 = 5,
    .pin_vsync = 25,
    .pin_href = 23,
    .pin_pclk = 22,
    .xclk_freq_hz = 20000000,
    .ledc_timer = LEDC_TIMER_0,
    .ledc_channel = LEDC_CHANNEL_0,
    .pixel_format = PIXFORMAT_JPEG,
    .frame_size = FRAMESIZE_SVGA,
    .jpeg_quality = 12,
    .fb_count = 1,
    .fb_location = CAMERA_FB_IN_PSRAM,
    .grab_mode = CAMERA_GRAB_WHEN_EMPTY,
};

static const char CMD_ON[] = "CX ON\r\n";
static const char CMD_OFF[] = "CX OFF\r\n";
static const char RESP_OK[] = "OK\r\n";
static const char RESP_DONE[] = "DONE\r\n";

static bool camera_active = false;

void send_jpeg() {
    camera_fb_t *fb = esp_camera_fb_get();
    if (!fb) {
        Serial.write(RESP_OK);
        return;
    }

    uint8_t hdr[6] = {0xAA, 0xBB};
    uint32_t len = fb->len;
    hdr[2] = (len >> 24) & 0xFF;
    hdr[3] = (len >> 16) & 0xFF;
    hdr[4] = (len >> 8) & 0xFF;
    hdr[5] = len & 0xFF;

    WRITE_PERI_REG(RTC_CNTL_BROWN_OUT_REG, 0);
    Serial.write(hdr, 6);
    Serial.write(fb->buf, fb->len);
    esp_camera_fb_return(fb);
    WRITE_PERI_REG(RTC_CNTL_BROWN_OUT_REG, 1);

    Serial.write(RESP_DONE);
}

void camera_power(bool on) {
    if (on && !camera_active) {
        esp_camera_init(&camera_config);
        sensor_t *s = esp_camera_sensor_get();
        s->set_framesize(s, FRAMESIZE_SVGA);
        camera_active = true;
    } else if (!on && camera_active) {
        esp_camera_deinit();
        camera_active = false;
    }
}

void setup() {
    WRITE_PERI_REG(RTC_CNTL_BROWN_OUT_REG, 1);
    pinMode(FLASH_LED, OUTPUT);
    digitalWrite(FLASH_LED, LOW);

    Serial.begin(CAM_BAUD);
    Serial.setTimeout(100);

    pinMode(4, OUTPUT);  // flash
    digitalWrite(4, LOW);
}

void loop() {
    static char buf[32];
    static int idx = 0;

    while (Serial.available()) {
        char c = Serial.read();
        if (idx < (int)sizeof(buf) - 1) buf[idx++] = c;

        if (c == '\n') {
            buf[idx] = '\0';
            idx = 0;

            if (strcmp(buf, CMD_ON) == 0) {
                camera_power(true);
                digitalWrite(FLASH_LED, HIGH);
                delay(200);
                send_jpeg();
                digitalWrite(FLASH_LED, LOW);
            } else if (strcmp(buf, CMD_OFF) == 0) {
                camera_power(false);
                Serial.write(RESP_OK);
            }
        }
    }
}

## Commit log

2026-06-08 Al-Idrisi-M1: CanSat Flight Control System
    - Dual-ESP32 flight firmware (main ESP32 + ESP32-CAM)
    - 22-field CSV LoRa telemetry protocol
    - 3D-printable parametric OpenSCAD enclosure (67mm OD, 120mm)
    - PyQt6 GCS with real-time plots, 3D visualizer, simulation mode
    - Full README with beginner + engineer documentation
    [sample_pressure.csv]
2026-06-08 Add cansat_enclosure.3mf (exported STL for slicing)
    [cansat_enclosure.3mf]
2026-06-08 Add cansat_enclosure.stl (STL mesh for slicing)
    [cansat_enclosure.stl]
